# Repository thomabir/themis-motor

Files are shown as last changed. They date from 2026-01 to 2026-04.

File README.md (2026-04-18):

# Themis Telescope Mount

Hardware and software for a direct-drive brushless DC motor and encoder for a telescope mount

## Control Scheme

- PWM
  - 50 to 100 kHz
  - Input: desired PWM duty cycle
  - Output: PWM signals to gate drivers
- Inner Loop: Current Control (FOC)
  - Controls flux and torque currents.
  - Runs at 10–20 kHz.
  - Inputs: Torque target (from position control loop), Phase current measurements (from current sensor), rotor electrical angle (from encoder).
  - Outputs: PWM duty cycles via inverse Park/Clarke
- Outer Loop: Position Control
  - Controls angular position and/or velocity, which is commanded from the observatory
  - Runs at 100–500 Hz.
  - Inputs: Position setpoint, measured position from encoder
  - Output: Torque command

## Motor Specifications

- Type: BLDC, direct drive (salvaged from a hoverboard)
- Quantity: 2 motors
- Electrical: 3 Phases, 30 Poles, 27 Slots, 36 V, 13 A RMS peak, 7A RMS continuous, 0.45 Ω, Y
- Mechanical: ≈ 10 Nm continuous, ≈ 1.43 Nm/A, ≈ 16 rpm/V, 350 W (estimates, not necessarily accurate)

## Encoder

DIY inductosyn, 0.05 arcseconds resolution, 1000 Hz sampling rate, custom SPI-like interface with absolute position, latency 1 ms.

## System Requirements

- Telescope Alt/Az axis control
- Tracking speed: 1 rev / 24 hr
- Slewing speed: 1 rev / 10 s
- Tracking error: < 1 arcsecond RMS
- Power: Mains
- System inertia: Low (balanced 8" SCT)

Thermal: motor will be at low currents most of the time, so convection will probably be fine, with short peaks when slewing. (Motors are from a hoverboard, which was also only passively cooled)

Mechanical: Very low backlash; bearing friction (esp. static) likely to influence control scheme.

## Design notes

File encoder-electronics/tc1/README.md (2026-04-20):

# Themis TC1

Goal: Figure out whether 10 kHz amplitude modulaiton works with the AD9834 DDS via the FS_ADJUST pin.

Secondary goal (optional): Have a minimal "sender" circuit for the encoder, test the differential driver

- Interfaces:
  - Power in: 4V lab PSU, ±13V lab PSU
  - Signal out: differential amplified DDS signal, can power the existing encoder coils
  - Digital IO: Every useful digital pin from the DDS is accessible via a pin header, for easy debugging
  - Testpoints: Every single analog signal is accessible, and jumpers between main sections are used for easy disconnecting of blocks.

- Strategy
  - Passives: Use 0Ωs and DNPs to keep it flexible. 0805 everything for easy modification by hand.
  - Using screw terminals for power and encoder, pin headers for digital. Not fancy, but cheap and quick.

- Power:
  - ±12 V: LT3097
    - 10 CHF/pc (= 5 CHF/rail)
    - 500 mA bipolar adjustable ultra-low-noise LDO
    - It's the best. Slightly pricy, but just works, no fuss.
    - Basically excludes LDOs as a noise source -> faster prototyping.
    - (Hurts a bit to buy fancy parts for a prototype)
  - 3.3 V: MAX8887
    - I've used it before -> copy-paste design
    - Decently low-noise
- DDS: AD9834
  - The big unknown: Can it modulate quickly and with low noise?
  - Does the differential output work as expected?
  - How to program it? Will figure out once I get it
- Clock: Active crystal oscillator at 75 MHz
- Diff-amp to drive encoder: AD8390
  - Lots of power, cheap, fast
  - Unknown: Made for ADSL, let's see if this works well in this application? Spec wise, it should work.

## How to run

Upload code to Teensy: `~/.platformio/penv/bin/pio run -e teensy41 -t upload`

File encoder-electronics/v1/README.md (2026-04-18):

# Themis Encoder Controller V1

A prototype board to prove the encoder concept.

Goal: Measure at the precision required for telescope tracking. Find the limiting factors.

## Concept

- Generate two 0.6 Vpp sines with DDS, in the 100 kHz to 3 MHz region (λ/10 < 5 m)
  - TX1: f0 carrier, amplitude modulated with f1, resonant with the encoder
  - TX2: f0 carrier, amplitude modulated with f2, resonant with the encoder
  - keep f2, f1 < 20 kHz, such that it's comfortably in the 32 kHz BW of the ADC
- Amplifiy all to 5 Vpp, 50 mA compliance
- TX signals are fed into the encoder via STP instrumentation cables
- RX signals are fed out of the encoder with STP instrumentation cables
- A differential amplifier receives the RX signals and amplifies them to a few Vpp (variable gain, depending on encoder used)
- Two mixers demodulate the AM signals
- An active band-pass filter removes the LO and DC and outputs the signal in ± 1V range
- A simultaneous sampling sigma-delta ADC samples the downmixed RX signals
- The uC demodulates in the digital domain
- The DDS clock and ADC sampling are phase-coherent, such that the freuquencies arrinving at the uC are deterministic.

## Advantages

- Processing at AC instead of at DC -> no susceptibility to slow drifts and 1/f noise
- High pole count -> higher resolution and lower susceptibility to random errors
- Tuned RF section for highest coupling efficiency, and low coupling of noise at other freuquencies

## Challenges

- Clocks synchronization strategy for DDS, ADC, uC etc.
  - The DDSs run on their own clocks (e.g. from clock generator), small drifts don't matter
  - The uC generates
    - a 8.129 MHz for the Sigma-Delta ADC clock
    - the PWM signals that control the amplitude modulation of the DDSs
      - the sin/cos LUT used for demodulation are also used for generating the PWM amplitude modulation signal
  - The uC runs on its own clock, and samples on /DRDY from the ADC (interrupt)
- crosstalk between all pairwise combinations of the four channels (2x RX, 2x TX) has to be low, so good shielding is essential
  - Be aware of returns currents in the ground plane
- It might be hard to get the analog signal chain right the first time on the PCB, without prototyping on breadboard first
  - Put [pin headers](https://www.digikey.ch/de/products/detail/w%C3%BCrth-elektronik/61300211121/4846823) and [jumpers](https://www.digikey.ch/de/products/detail/sullins-connector-solutions/QPC02SXGN-RC/2618262) on every important signal and power connection, such that it is essentially modularized
  - Can easily probe sections in isolation without having to cut traces or desolder

## Key components

### Power (LDOs)

### Signal generation

Requirement: Up to 3 MHz sine.

#### DDS

- Current choice: [AD9834](https://www.analog.com/media/en/technical-documentation/data-sheets/AD9834.pdf)
  - 14 CHF * 2 = 28 CHF total
  - Supply 2.3 to 5.5 V (AVDD and DVDD indpendent)
  - 75 MS/s, 10 Bit
  - 2.5 MHz signal: strongest image -30 dB
  - MCLK: up to 75 MHz
  - Vout: 30 mV to 0.6 V
  - It has an FSadjust pin, which can be used for amplitude modulation
    - App note: [It works at DC](https://www.analog.com/media/en/reference-design-documentation/reference-designs/cn0156.pdf)
    - May have to decrease COMP cap for 10 kHz modulation: [EEVblog forum](https://www.eevblog.com/forum/projects/amplitude-modulation-of-ad9834-dds-failed-but-why/25/)
    - Differential outputs: [EEVblog forum](https://www.eevblog.com/forum/repair/low-cost-signal-generator-with-modulation-is-that-a-pink-elephant)
- AD9838
  - BW: 8 MHz
  - 7 CHF
  - no FS ADJUST -> not an option
- AD9837
  - 6 CHF, hard to notice any practical difference to AD9838
  - 8 MHz bandwidth
  - 0.6 Vpp typ
  - 200Ω Rout (current source with 200Ω to ground after it -> Thevenin is a voltage source with 200Ω output impedance)
    - needs a buffer to drive the encoder (1µH, 1Ω, 1nF)
  - has image at nyquist - fout, but that will be filtered out during downconversion
    - however, LO has to be clean. Should think about this a bit more
  - 2.5 MHz signal: strongest image at -15 dB, 13.5 MHz
  - 2.3 to 5.5 V power supply
  - No FS ADJUST -> not an option

#### Clock generator

- [TI CDCE6214](https://www.ti.com/lit/ds/symlink/cdce6214.pdf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)
  - 5.70 CHF
  - same as in analog discovery 3
- [Si5351A](https://cdn-shop.adafruit.com/datasheets/Si5351.pdf): 1.7 CHF, can generate 4 clocks from kHz to 10s of MHz
  - [Adafruit breakout board](https://www.adafruit.com/product/2045)
  - Z_out: 50 Ω
  - Supply 3.3 V
  - RMS phase jitter (12 kHz to 20 MHz): 3.5 ps typ
  - Pk cycle-to-cycle jitter (10 k cycles): 30 ps typ
  - Crystal requirements: 25 to 27 MHz, 6 to 12 pF

### Amplifiers

- Requirement
  - Gain 10 at 3 MHz (30 MHz GBWP)
  - Slew rate: `2π * 5V * 3 MHz` = 100 V/µs
  - Power: ±18 V min.
- Main op-amp: [LM6172](https://www.ti.com/lit/ds/symlink/lm6172.pdf)
  - stable with 1 nF load
  - dual opamp
  - -65 dB crosstalk rejection at 3 MHz
  - fast enough
  - 50 mA continuous output current
  - DIP package available for easy breadboarding
  - 33 CHF for 10 pc
- stronger TX amplifier/buffer: OPA2673
  - Supplies: ± 3.5 to ± 6.5 V -> analog chain is ± 5 V, because nice number
  - Output: 700 mA, 3500 V/µs (way overpowered most likely, very conservative)
  - 600 MHZ unity gain bandwidth
- full-wave diode mixer (can be skipped with jumpers, then can use breadboard mixer as alternative)

### ADC

- [ADS131M03](https://www.ti.com/lit/ds/symlink/ads131m03-q1.pdf)
  - 3ch 64 kS/s Sigma-Delta
  - 8.192 MHz MCLK in
  - Supply: 2.7 to 3.6 V -> using 3.3V
  - Integrated charge pump to allow negative input voltages
    - Note that this is unusual, but simplifies the setup considerably.
    - Max absolute ratings on AINP, AINN: AGND – 1.6V to AVDD + 0.3V
    - Recommended voltage  on AINP, AINN: AGND – 1.3V to AVDD
    - Current limit to ±10mA max: ±6V into 1kΩ yield 6mA, should be safe
  - Integrated reference: 1.2V
  - Full scale range: ±1.2V (1x gain) to ±9.3mV (128x gain)
  - 330 kΩ input impedance at gains from 1 to 4
  - Noise and dynamic range (p. 16 datasheet)
    - At  1x gain, 64 kS/s: 80 dB dynamic range, 75 µV RMS noise
    - At 32x gain, 64 kS/s: 60 dB dynamic range, 5.58 µV RMS noise
    - don't go higher in gain, no benefit
  - channel corsstalk < -125 dB
  - power: < 3mA analog, < 0.5 mA digital apparently (p. 15 of datasheet)

## Signals and noise

- DDS: 600 mVpp (300 mV amplitude)
- TX amps: amplify to 5 Vpp
- encoder board: 0.3x gain (measured at 2.5 MHz with 10 nF, see lab notebook 2025-11-03)
- RX amps: switchable from 1x to 10x gain (or potentiometer)
- model mixer in LTspice, then low-pass
- ADC: ± 1 V amplitude target pseudo-differential (connect GND to AINN) (headroom to ±1.2V reference)

## Power and voltages

- Analog voltages: ±9V (except ADC)
- ADC and DDS: +3.3V (both analog and digital)
- ADC inputs ±1.2V differential max.
- Protect ADC against overvoltage

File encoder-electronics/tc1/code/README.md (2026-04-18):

# TC1: DDS

## Concept

Outputs:

- 8.192 MHz clock for ADC
- 2x PWM signals for FS_ADJUST (kHz to 10 kHz range)

Inputs:

- Data_Ready from ADC (≈ 64 kHz, the ADC derives it from the 8.192 MHz clock)
- SPI data from ADC

Setup:

- Populate LUTs for FS_ADJUST
- Start ADC clock

Main loop (no DMA):

- Wait for DREADY
- Read ADC
- Demodulate and downsample data (using LUT values)
- Load new duty-cycle for FS_ADJUST from LUT

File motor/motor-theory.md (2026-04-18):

# Motor Theory

Torque equation:
$$
T = \frac{3}{2} p \phi I
$$

## Derivation of torque equation

The net power flow of the system is the following:
Electrical power enters the system, and it leaves as mechanical power and thermal power.

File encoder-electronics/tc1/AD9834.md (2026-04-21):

# AD9834 DDS — Field Notes

MCLK on TC1: **75 MHz** (BOM correct, schematic had 50 MHz — corrected).

SPI interface: SCLK idles high, data latched on falling edge, MSB first, 16-bit words, write-only (no MISO).
notFSYNC (active low) frames each 16-bit transfer individually.

The AD9834 datasheet describes this as CPOL=0, CPHA=1 — which is **opposite** to the Arduino/standard convention. In Arduino terms this is **SPI_MODE2** (CPOL=1, CPHA=0). Use `SPI_MODE2` in `SPISettings`.

## Register addressing (DB15:DB14)

| DB15 | DB14 | Target |
|---|---|---|
| 0 | 0 | Control register |
| 0 | 1 | FREQ0 |
| 1 | 0 | FREQ1 |
| 1 | 1 | PHASE (DB13 selects PHASE0/PHASE1) |

## Control register (DB15:DB14 = 00)

| Bit | Name | Description |
|-----|---|---|
| DB13 | B28 | 1 = 28-bit frequency write (two consecutive 16-bit words, LSB first then MSB). 0 = 14-bit half-word mode (use HLB to select half) |
| DB12 | HLB | When B28=0: 1 = write MSBs, 0 = write LSBs. Ignored when B28=1 |
| DB11 | FSEL | 0 = use FREQ0, 1 = use FREQ1 in phase accumulator |
| DB10 | PSEL | 0 = use PHASE0, 1 = use PHASE1 |
| DB9 | PIN/SW | 0 = software control (use control bits), 1 = hardware pin control |
| DB8 | RESET | 1 = reset internal registers → DAC output at midscale |
| DB7 | SLEEP1 | 1 = disable MCLK |
| DB6 | SLEEP12 | 1 = power down DAC |
| DB5 | OPBITEN | 1 = **enable SIGN BIT OUT pin**. Must be 0 if MODE=1. Pin is high-Z when 0 |
| DB4 | SIGN/PIB | 1 = comparator output on SIGN BIT OUT, 0 = MSB (or MSB/2) of DAC data |
| DB3 | DIV2 | When SIGN/PIB=0: 1 = MSB direct, 0 = MSB/2 |
| DB2 | — | Reserved, always 0 |
| DB1 | MODE | 0 = sine (SIN ROM active), 1 = triangle (SIN ROM bypassed). Must be 0 if OPBITEN=1 |
| DB0 | — | Reserved, always 0 |

Useful control word constants:

| Value | Effect |
|---|---|
| `0x2100` | B28=1, RESET=1 — reset device |
| `0x2000` | B28=1, FSEL=0, sine output, SIGN BIT OUT disabled |
| `0x2002` | B28=1, FSEL=0, triangle output (MODE=DB1), SIGN BIT OUT disabled |
| `0x2800` | B28=1, FSEL=1, sine output, SIGN BIT OUT disabled |
| `0x0028` | OPBITEN=1 (DB5), DIV2=1 (DB3) — SIGN BIT OUT at f_out (no B28, use as tail-word in freq update) |
| `0x0038` | OPBITEN=1 (DB5), SIGN/PIB=1 (DB4), DIV2=1 (DB3) — SIGN BIT OUT via comparator (VIN path) |

## Frequency registers

With B28=1 (28-bit mode), write two consecutive words to the same register address:
1. First word: `reg_addr | (freq_word & 0x3FFF)` — 14 LSBs
2. Second word: `reg_addr | ((freq_word >> 14) & 0x3FFF)` — 14 MSBs

Frequency word: `freq_word = round(f_out / f_MCLK * 2^28)`

Example for 1 MHz with 75 MHz MCLK: `freq_word = 3,579,139`

## SIGN BIT OUT (SIGNOUT) pin

**SIGNOUT is high-impedance at power-up** (OPBITEN=0 default). Any signal seen on it before config is parasitic coupling on the floating pin — not a real output.

To enable: set OPBITEN=1 in control register. MODE must be 0.

SIGN/PIB=1, DIV2=1 gives a comparator-derived square wave — useful as a quick proof-of-life check at the DDS output frequency.

## FS_ADJUST pin

Analog input setting full-scale DAC output current:
`I_OUT_FS = 18 × V_FSADJ / R_ADJUST`

Datasheet default: 6.8 kΩ from FS_ADJUST to AGND.
On TC1: driven by Teensy PWM (pin 6) through an on-board low-pass filter. Disconnect or float FS_ADJUST only temporarily for debugging; the full-scale current is undefined when floating.

## Startup sequence

1. Assert RESET: send `0x2100`
2. Write frequency register (two words for 28-bit mode)
3. Write phase register if needed (default 0 is fine)
4. Deassert RESET and configure output: e.g. `0x2028` (sine, SIGNOUT enabled via comparator)

## TC1 wiring (Teensy 4.1 → board header)

| Board pin | Teensy pin | Function |
|---|---|---|
| SDATA | 11 | MOSI |
| SCLK | 13 | SCK |
| notFSYNC | 10 | CS (active low) |
| RESET | 9 | GPIO — **must be driven LOW (OUTPUT) before initialising DDS** |
| FS_ADJUST | 6 | PWM output |

## Known issues / lessons learned

- **RESET pin must be driven LOW before initialising the DDS.** A floating RESET pin held the chip in reset throughout TC1 bringup — all SPI writes were ignored, SIGNOUT was silent. Root cause: the AD9834 constructor was also being called at global scope (before Arduino `setup()`), meaning SPI was not yet initialised. Fix: construct the DDS object inside `setup()`, and drive RESET LOW explicitly before doing so.
- SIGNOUT must be broken out on the next board revision — essential for proof-of-life since the AD9834 has no readback (SPI is write-only).
- **SIGNOUT is high-Z at power-up** (OPBITEN=0). Any signal seen before config is parasitic coupling on the floating pin. Silence after config means OPBITEN was never written — check SPI first.
- ~~The library's `update_freq_reg` ends with control word `0x38` (OPBITEN=1, SIGN/PIB=1, DIV2=1, B28=0, FSEL=0). This enables SIGNOUT as a comparator output but leaves B28=0 after each call.~~ **Fixed (2026-04-21):** the FSELECT-switch tail-word is now built from named bit constants and carries the current output mode correctly. B28 is no longer cleared after a frequency update.
- The AD9834 uses a non-standard CPOL/CPHA labelling (CPOL=0, CPHA=1 in their docs = Arduino SPI_MODE2). Don't set the SPI mode from the datasheet labels directly.
- Digital supply current: ~13 mA idle, ~17 mA when DDS is active and outputting.

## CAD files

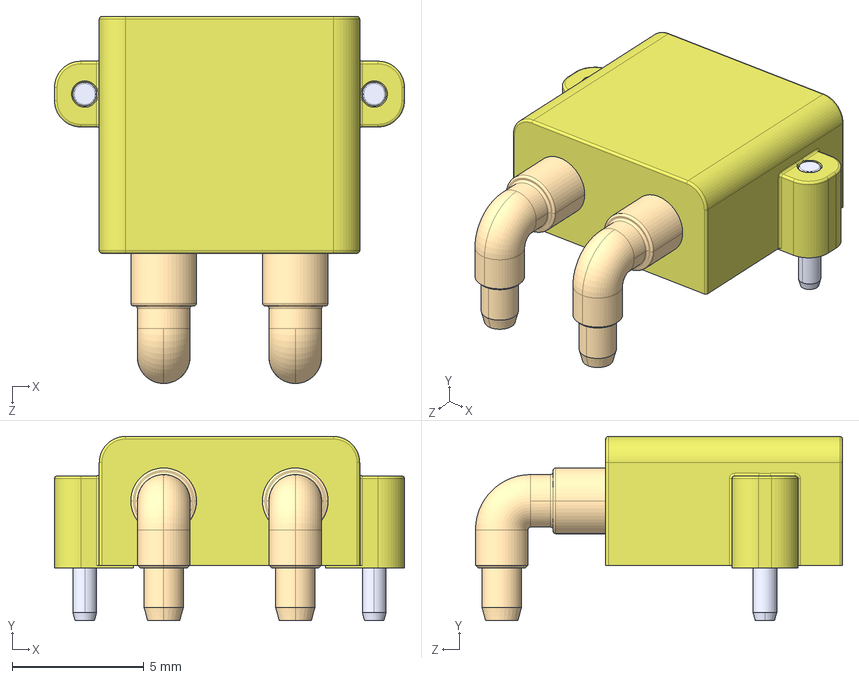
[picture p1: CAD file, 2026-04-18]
motor-controller/v3/kicad/3d-models/XT30PW-M.STEP
13.3 x 7.00 x 14.0 mm

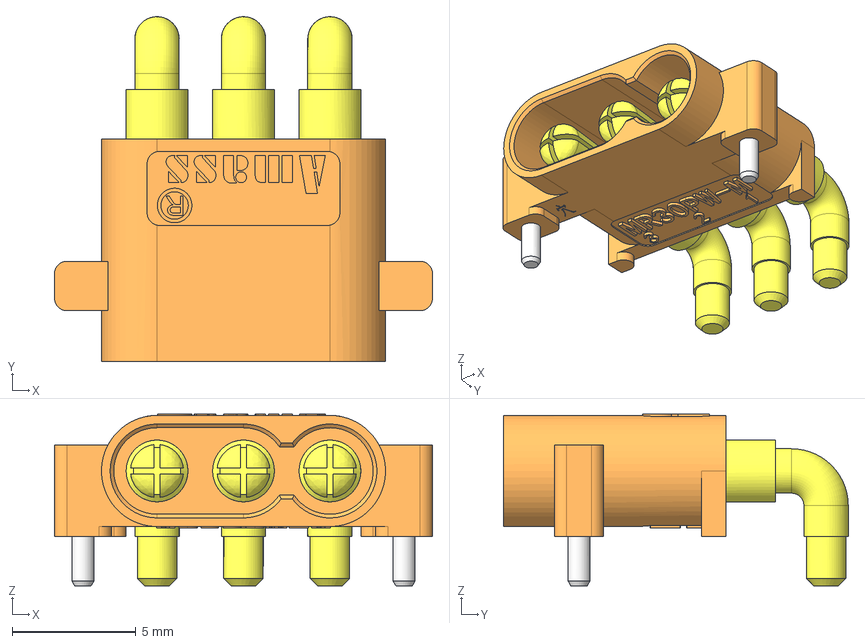
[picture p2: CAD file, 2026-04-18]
motor-controller/v3/kicad/3d-models/MR30PW-M.step
15.3 x 13.9 x 6.95 mm

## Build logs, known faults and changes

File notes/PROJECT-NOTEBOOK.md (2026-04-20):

# Themis Project Notebook

## 2026-06-20

### Getting 1 MHz DDS output

- Measured clock: 75 MHz, ≈ 3 Vpp (not great probing, so amplitude not certain)
  - Problem: This is a discrepency with schematic, which says 50 MHz. Not a big issue
  - BOM part number is a 75 MHz part, so the procurement was correct. Updating schematic.
  - Changed MCLK_HZ in code to 75 MHz
- Measuring SIGNOUT pin
  - 8.7 MHz 3.3V clock, distorted probably from bad probing
  - After configuring for 1 MHz with Teensy: Still 8.7 MHz.
  - This is not as expected, something's wrong. Should be 1 MHz
- Soldered 6.8 kΩ resistor between FSADJUST and GND.
- Clock still as before
- SIGNOUT now no output, both before and after config from uC.
- Did the part die?
- Prepared second board, also soldered in 6.8 kΩ resistor between FS_ADJUST and GND
  - Clock good
  - no SIGNOUT output before teensy config
  - no SIGNOUT output after teensy config
- Removng 6.8 kΩ resistor again
  - clock still good
  - still no SIGNOUT output
- What happened here? Did both boards die from soldering in a resistor?

- Desoldered 6.8 kΩ again on one of the boards. I broke out these pins on the PCB, so the resistor has big pads and is nowhere near the IC. No bridges possible here
- Inspected both boards under microscope. No problems visible. Some crud from probing the SIGNOUT pin at the IC (forgot to break that one out), but no bridging. Cleaned up a bit anyway with small scaper.
  - Next board iteration: break out SIGNOUT pin
- ICs are not getting warm. Lab PSU shows < 10 mA on analog rails. No current measurement on digital rails unfortunately. Switching Lab PSU to get that as well.
- Digital rail draws 13 mA, probably not a short.
- Next: Checking SPI

- From AD9834 datasheet:
  "SIGN BIT OUT PIN
  The AD9834 offers a variety of outputs from the chip. The digital outputs are available from the SIGN BIT OUT pin. The available outputs are the comparator output or the MSB of the DAC data. The bits controlling the SIGN BIT OUT pin are outlined in Table 17.
  This pin must be enabled before use. The enabling/disabling of this pin is controlled by the Bit OPBITEN (DB5) in the control register. When OPBITEN = 1, this pin is enabled. Note that the MODE bit (DB1) in the control register should be set to 0 if OPBITEN = 1."
- It appears what I measured before (8.7 MHz SIGNOUT) may have been some parasitic coupling.

- Scoping SPI signals with AD3 now to see if they are as expected.
- Not stable, very noisy, one capture:
  `h4101 h1907 h01B5 h1971`
  SCLK freq ≈ 10 MHz
- Weird, I've used 10 MHz SPI over jumpers in the past, no problem.
- SPI clock slowed down to 1 MHz
  - still garbled data, changes on every transmission
  - Disconnected DUT now - just probing SPI from teensy directly.
  - That clock frequency is not a problem now - 1 MHz is very slow
- Found a problem: was probing SPI wrong. In AD9834 datasheet: "SCK idles high between write operations (CPOL = 0), Data is valid on the SCK falling edge (CPHA = 1). notFSYNC (active low) frames each 16-bit transfer individually."
- When I set the logic analyzer up for that, it's a bit more stable:
  ```
  b0010000000000000
  bXX01110100000011
  bXX00000011011010
  b0000X00000111000
  ```
  (X means unstable, jumping around)

- Just realized: RESET pin was floating the entire time. Setting it now and reuploading code.
- SIGNOUT is alive! 9.7 MHz 3.3V
- Power consumption just changed: 17 mA digital.
- DDS+ and DDS- show a clean 1 MHz signal!
- That fixed it, floating reset pin was the culprit.

### Testing amplifier function

- I get a clean 1 MHz signal between the AMP+ and AMP- pins
  - 10.45 Vpp, 3.67 Vrms
- Good output at output terminals (after resonant capacitor)
  - 10.35 Vpp, 3.64 Vrms

### Testing modulation via FS_ADJUST

- Signals from PWM + low-pass appear quite noisy. Push PWM freq. as fast as possible.

### Notes for the future

- What worked well
  - Power section: flawless so far
  - Having lots of GND testpoints, very convenient
  - Breaking out many signals as testpoints - makes probing easier, but also soldering in other components like R_SET

- What to improve
  - make connectors (power, data) quick-disconnectable (use the plug-in type screw terminals instead of regular ones)
  - Break out more pins for easy testing, especially for unknown ICs
  - Leave some footprints to be able to set up ICs with "default" components, in case my config does not work, and mark as DNP
  - Cross-check BOM with schematic (50 vs 75 MHz clock)
  - Don't leave the reset pin floating

## 2026-04-18

TC1 testings

[X] Voltage regulators are working
  [X] +12 V (less than 10 mA idle)
  [X] -12 V (less than 10 mA idle)
  [X] +3.3 V

Should have broken out the SIGNBIT pin from the AD9834 for proof-of-life, since there is no SDO.

Currently, using datasheet-suggested 6.8 kΩ resistor from FSADJUST to GND instead of PWM.

Setting up for 1 MHz sine wave. Output not good. See spikes at 1 MHz, but a lot of noise. Not a sine wave.

## 2026-04-17

Assembling TC1 (Transmitter)

Ibom had some wrong values, used to ones from the schematic instead.
  For C13, I'm using 10u instead of 2.2u
  For R12, R13 I'm using 22 Ω instead of 25 Ω

## 2026-01-01

TC1 sent off for manufacturing.
RX: Using AD8130 in-amp. Rest of chain I have in LTspice, still need an opamp choice, but not critical.
Work on ADC, schematic etc.

Firmware for DDS and ADC.

## 2025-12-30 Test Coupon 1: DDS Amplitude Modulation

Goal: Figure out whether 10 kHz amplitude modulaiton works with the AD9834 DDS via the FS_ADJUST pin.

Secondary goal (optional): Have a minimal "sender" circuit for the encoder, test the differential driver

- Interfaces:
  - Power in: 5V lab PSU
  - Signal out: amplified DDS signal, can power the encoder
  - Digital IO: Every single digital pin from the DDS is accessible via a pin header, for easy debugging
  - Testpoints: Every single signal is accessible, and jumpers between main sections are used for easy disconnecting of blocks.

- Power:
  - LDO for 5V -> 3.3V to supply DDS
  - LDO for ±X V -> supplies amplifier

## 2025-12-29 Getting un-stuck

- To avoid analysis paralysis, I have to get a board out for manufacturing soon.
- I'm setting a hypothetical hourly rate for myself, to avoid spending too much time in simulation and concept phase.
  - 10 CHF set-up fee (whenever I start working or thinking on the project)
  - 30 CHF/hour (min. 1h)
- Deadlines
  - [DONE] Today (Dec 29), I have identified the SGU (Single Greatest Unknown), and dedicate to building a TC (Test Coupon) to test this specific thing.
  - [TODO] Sunday 20:00 (Jan 4) at the latest, I send out Test Coupon #1 for manufacturing. If this does not happen, I trash the project.

- SGU (Single Greatest Unknowns):
  - Candidates:
    - Analog part choice
    - Filters
    - noise
    - amplification
    - oscillation/stability
    - uC interface to ADC/DAC
    - Power supply
    - Mounting/mechanical
    - DDS control via modulation port
    - Clock generator for DDS
    - Clock synchronization (DDS modulation -> ADC Sigma-Delta sampling clock)
    - uC internal code (DSP etc.)
    - Current return path / ground noise
    - Interference/EMI
    - Cables/shielding
    - Connectors
    - Encoder coils analog model
  - Shortlist:
    - Analog chain concept: Get a signal from a signal generator, amplify it to get it into the encoder, amplify and mix down the response, look at it on the scope. NO: I basically already did that on breadboard, only one buffer was missing honestly. I have high confidence this will work. I trust the concept.
    - Analog chain implementation: Instead of breadboard, use the real SMD components, characterise the noise levels, test the amplification gain of the stages. Make sure nothing oscillates. No digital parts on board. NO: I realise I am mostly anxious to test the digital part, which I don’t have any experience with.
    - Digital section: I have never worked with a crystal oscillator before (shocking, I know), and I have two DSS’s and an ADC, all of which need sync’d clocks or control inputs from the uC. Goal: Get the individual digital parts working with their clocks synchronised and correct control signals from the uC. Slap on a basic analog section, first guess, and be ready to just swap out the analog part for something better in a separate TC. Just measure SOMETHING on the ADC that shows that the clocks are in phase, disregard noise. Use a Teensy dev-board
    - No, keep it even simpler: Make a AD9834 Test Coupon: Just the DDS, a basic amplifier for the output, and break out every single pin. This is the “warm-up” exercise. Goal: Get the amplitude modulation working with the FS_ADJUST pin. EEVblog forum members write that I may have to reduce COMP capacitor to make it work for my modulation frequency. This is something that I can’t figure out in LTspice, the datasheet does not mention it, thus it needs a physical test board. It’s crucial to figure this out: The encoder concept depends on being able to modulate the DSS output at 10 kHz or so. If it works: use it as a small board that is part of the encoder, or copy-paste the PCB design in with confidence wherever needed. If it doesn't work: I saved a lot of design time by identifiying the cuplrit early, the rest of the encoder would not have worked anyway!

- Oscillators 75 MHz for DDS: [digikey](https://www.digikey.ch/de/products/filter/oszillatoren/172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)

## 2025-12-02

- Finished analog chain in LTspice
- Mixer works at 200 kHz as well as 2.5 MHz, that part should be fine
- The only adjustable gain I need is at the RX amp, since it depends strongly on encoder size.
- PCB layout plan
  - Put everything on one PCB, 10x10 cm minimum size (larger is fine for easier bodging)
  - Separate into logical sections: DDS/ADC/clock generator/analog chain
    - Connect with traces that have a jumper on them, so can easily interrupt traces and connect other signals
    - (SMT jumpers would be great to save time)
    - this keeps it modular and still functional, even if part of the board fails

## 2025-11-30

Laying out the analog board in LTspice, selecting gains.
Considering the LM6172 as the do-it-all amplifier (50 mA current, fast, drives 1nF well)

## 2025-11-03

- Continued from yesterday
  - Realised I used 1 nF caps instead of 10 nF yesterday.
  - If I use 10 nF for sender and receiver, 10Ω series at sender for current limit, I get the expeceted peak around 2.5 MHz, gain ≈ 0.35 peak.
  - Still weaker than what I had on 2025-08-11, but at least there's a peak and it's at the expected frequency.
  - K ≈ 0.1 in LTspice seems a decent match for the behaviour I see.

Does this give me all the information I need to prototype the analog chain?

- Max. frequency and bandwidth: yes, 2.5 MHz should be fine, let's say 3 MHz for margin.
- LTspice model: yes, I have one that seems to reproduce the behaviour well (two 500 nH inductors, K = 0.1)
- Capacitors for resonant circuit: 10 nF on RX and TX
- Current compliance: Get it from LTspice model, AD3 had no problems in resonance with 1Vpp + 10Ω series resistor
- Noise levels: Don't know yet, best to build a prototype and measure.

So, what is the next step?

- Analog chain prototype: Gain stages, mixers, testpoints.
  - Frequencies come from a different board or AD3/signal generator
  - ADC also on a different board, differential via STP wire
- In more detail
  - Three input ports for TX1, TX2, LO
  - Power amplifiers for TX1, TX2 (+LO, might as well):
    - DDS output is in the range of 0.6 Vpp + 200 Ω impedance
    - Selectable gain with resistor or jumper: 1x, 5x, 10x?
    - current compliance 100 mA is plenty
    - voltage level? 3.3 V would be nice as it's universal, but analog chain may well be ±12 V or so if needed.
  - Outputs for amplified TX1, TX2: STP wire
  - Inputs for RX1, RX2
  - Amplifiers for RX1, RX2: not much power needed (driving diodes, see LTspice), selectable gain again. May be worth making these differential, not sure
  - Diode mixers with LO: double Schottkys for maximum efficiency
  - Low-pass filter: Prepare for a 64 kS/s sigma-delat ADC, so 100 kHz filter more than adequate.
    - Blessed art thou, sigma-delta ADC, for thy inherent filtering simplifies my analog chaine
  - That's all, folks.

Potential pitfalls

- Interference, crosstalk: Keep everything well separated, lots of ground planes, use STP wires.
  - 3 MHz is a long wavelength, lambda/10 ≈ 10 m
- Noise
  - measure and adapt, check with LTspice. Trust the physics
- PCB errors
  - Keep it modular: testpoints and jumpers everywhere, so every module can be skipped and isolated
  - keep the PCB big, so repairs and bodges are feasible
  - Use parts that I can hand-solder if neeeded (0805, SOIC ...)
- Oscillations, capacitive loads
  - Use recommended isolation resistors at TX amps for capacitive loads
  - Keep feedback loops tight
  - simulate in LTspice

What I need

- STP wires + some way to connect them to the board. Maybe just screw terminals + a crocodile clamp for shield to keep it simple.
- Decide on diff-amp vs opamp at RX: what are the trade-offs?
- PCB design + reflow

## 2025-11-02

Goal: Figure out the information I need to design the encoder board.

- Measure transfer function of current encoder, in a configuration that would be used for practical motor control.
  - This defines the maximum required frequency of the signal generators, as well as the minimum expected coupling
  - (A larger encoder will resonate at a lower frequency and have better coupling coefficient)
  - Read through lessons learned of previous attempts at measuring the encoder, make a checklist.
- Build up the whole system as far as possible.
  - What is missing? Probably need buffer amps: How much gain, bandwidth, current compliance needed? Which capacitive + inductive load?
  - How are the noise levels? Probably insufficient -> where does the noise come from? Cables? DDS? ICs?

### Encoder characterisation measurements

Goals: Get all information I need to design encoder electronics that interfaces with the encoder disks (DDS, RX and TX amplifiers)

This means I need:

- Measurements of L, R, C of the encoder (no resonant circuit, with resonant circuit)
- Measured impedance curve of encoder (no resonant circuit, with resonant circuit)
- Choice of capacitor/inductor to make the encoder resonant
- LTspice model of single encoder disk (no resonant circuit)
- LTspice model of full encoder system of two disks (no resonant circuit)
- Measured transfer function of two coupled disks under maximum coupling

Watch out:

- Keep wires short to avoid their parasitic impedance
- Use short/open compensation
- Check crosstalk and keep it low, this messed up some previous measurements
- Find optimum configuration with resonant circuit, then characterize.

Experiment 1: Impedance measurement of single encoder disk

- Used Analog Discovery 3, impedance measurement mode, 10 Ω resistor
- performed open and short calibration
- Sweep 1 kHz to 10 MHz with 1 V amplitude
- Results
  - Series inductance 0.4 µH to 0.6 µH from 10 kHz to 10 MHz
  - Series resistance: 0.9 Ω to 1.0 Ω from 10 kHz to 2 MHz, sharp rise afterwards
- The resistance is as expected constant and low. The rise at the end is weird
- Inductance is as expected constant and low (small encoder).
- Measurements agree with my previous measurements on 2025-05-17 of the same encoder, except for series inductance (was 0.65 to 0.75 µH).
  - I did however shorten the cables of the encoder from 40 cm to 20 cm today.
- Conclusion: use 0.5 µH series impedance + 1.0 Ω series resistance for modelling the disk.

Trying to reproduce 2025-08-11

- No resonant circuit: Hard to measure, around 0.6 V/V at 4 to 5 MHz is peak coupling.
  - Used a 10 Ω resistor in series with source, 1V amplitude. Still lots of distortion at lower frequencies.
- With resonant circuit, 10 nF in parallel with both sender and receiver
  - Very weird! I don't get a resonance peak. Very suspicious, probably something wrong here.
    - Looks like resonance at ≈ 10 MHz with 1:1 coupling
    - Nevermind, just crosstalk, signal remains even when I unplug the measurement leads on the RX
  - Should try with inductor as well, maybe that fixes it. But have I really forgotten to write that down in the entry from 2025-08-11?
  - I don't see a match with f0 = 1 / 2π sqrt(LC), very odd! This is not a missing inductor, something different is wrong here.

### Encoder analog chain prototype

Goal:  Get all information I need to design encoder electronics

This means I need:

- Try to build the full analog chain
- Check where I need additional gain or current compliance
- Measure noise and compare with expectation

## 2025-10-20

Have to figure out what voltage levels I expect at the RX: Do I need an amplifier/buffer there?
Should find that experimentally with the encoder I have.

## 2025-10-19: Solving the synchronisation problem

New maxim: Optimise for finishing, not for cost/time/effort

- Don't try to save money
- Use components that are easy to use (low pin count)
- Make recovery from mistakes easy
- uC/FPGA on external dev-board, header pins
- jumper-friendly PCBs such that broken sections can be skipped and replaced with breadboards
- use good cables and connectors to reduce mess and interference
- Use familiar tools (Zynq, lab pc, ImGui)

**Proposed solution for the clock synchronization problem:**

- A clock generator IC generates four signals
  - 50 MHz clock for a DDS, to generate a clean LO free of harmonics
  - f1 for the encoder (square wave) (or use DDS as well)
  - f2 for the encoder (sqaure wave) (or use DDS as well)
  - 8.129 MHz for the Sigma-Delta ADC clock
- The microcontroller or FPGA runs on its own clock, and samples on /DRDY from the ADC (interrupt)
  - The internal sin/cos LUT also is incremented at every /DRDY pulse
  - Or can also get it from clock generator, but for modularity's sake, I'll keep them separate until the design is more mature.

**Boards for prototyping:**

- PYNQ Z2 dev board for FPGA
- Custom PCB
  - Power (LDOs), external
  - Clock generator: Si5351A
  - DDS: AD9834
  - TX amplifiers/buffers: OPA2673
  - RX buffer: same or something less powerful
  - full-wave diode mixer (can be skipped with jumpers, then can use breadboard mixer as alternative)
  - ADC: ADS131M03 (3ch 64 kS/s)

The third ADC channel would be unused in this design, and could be used to make the encoder absolute with an additional basic low-resolution encoder with different pole count.

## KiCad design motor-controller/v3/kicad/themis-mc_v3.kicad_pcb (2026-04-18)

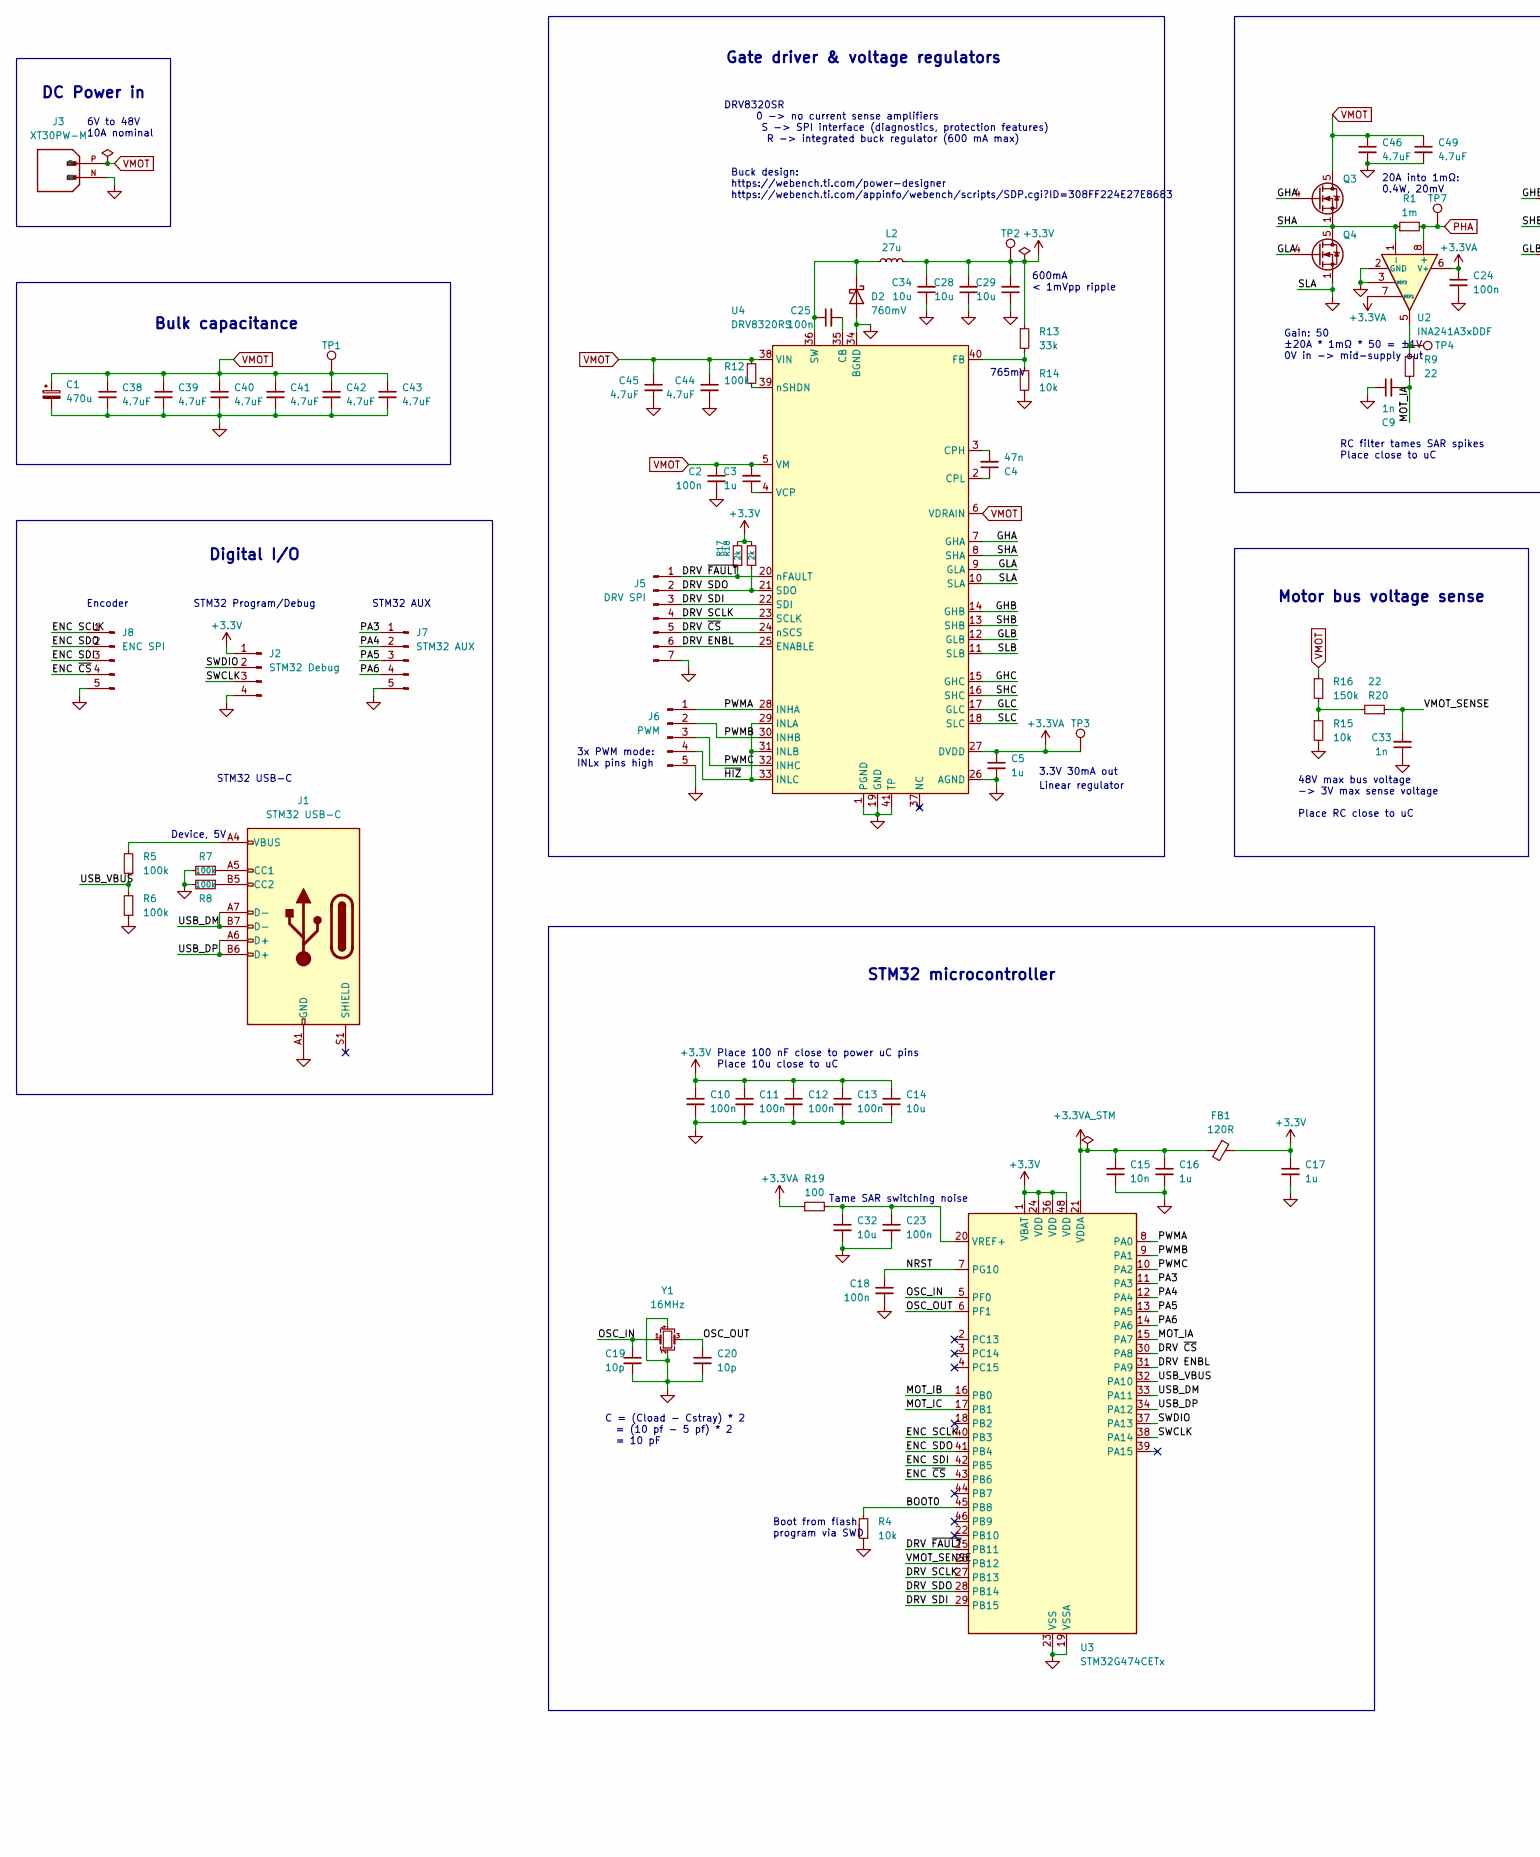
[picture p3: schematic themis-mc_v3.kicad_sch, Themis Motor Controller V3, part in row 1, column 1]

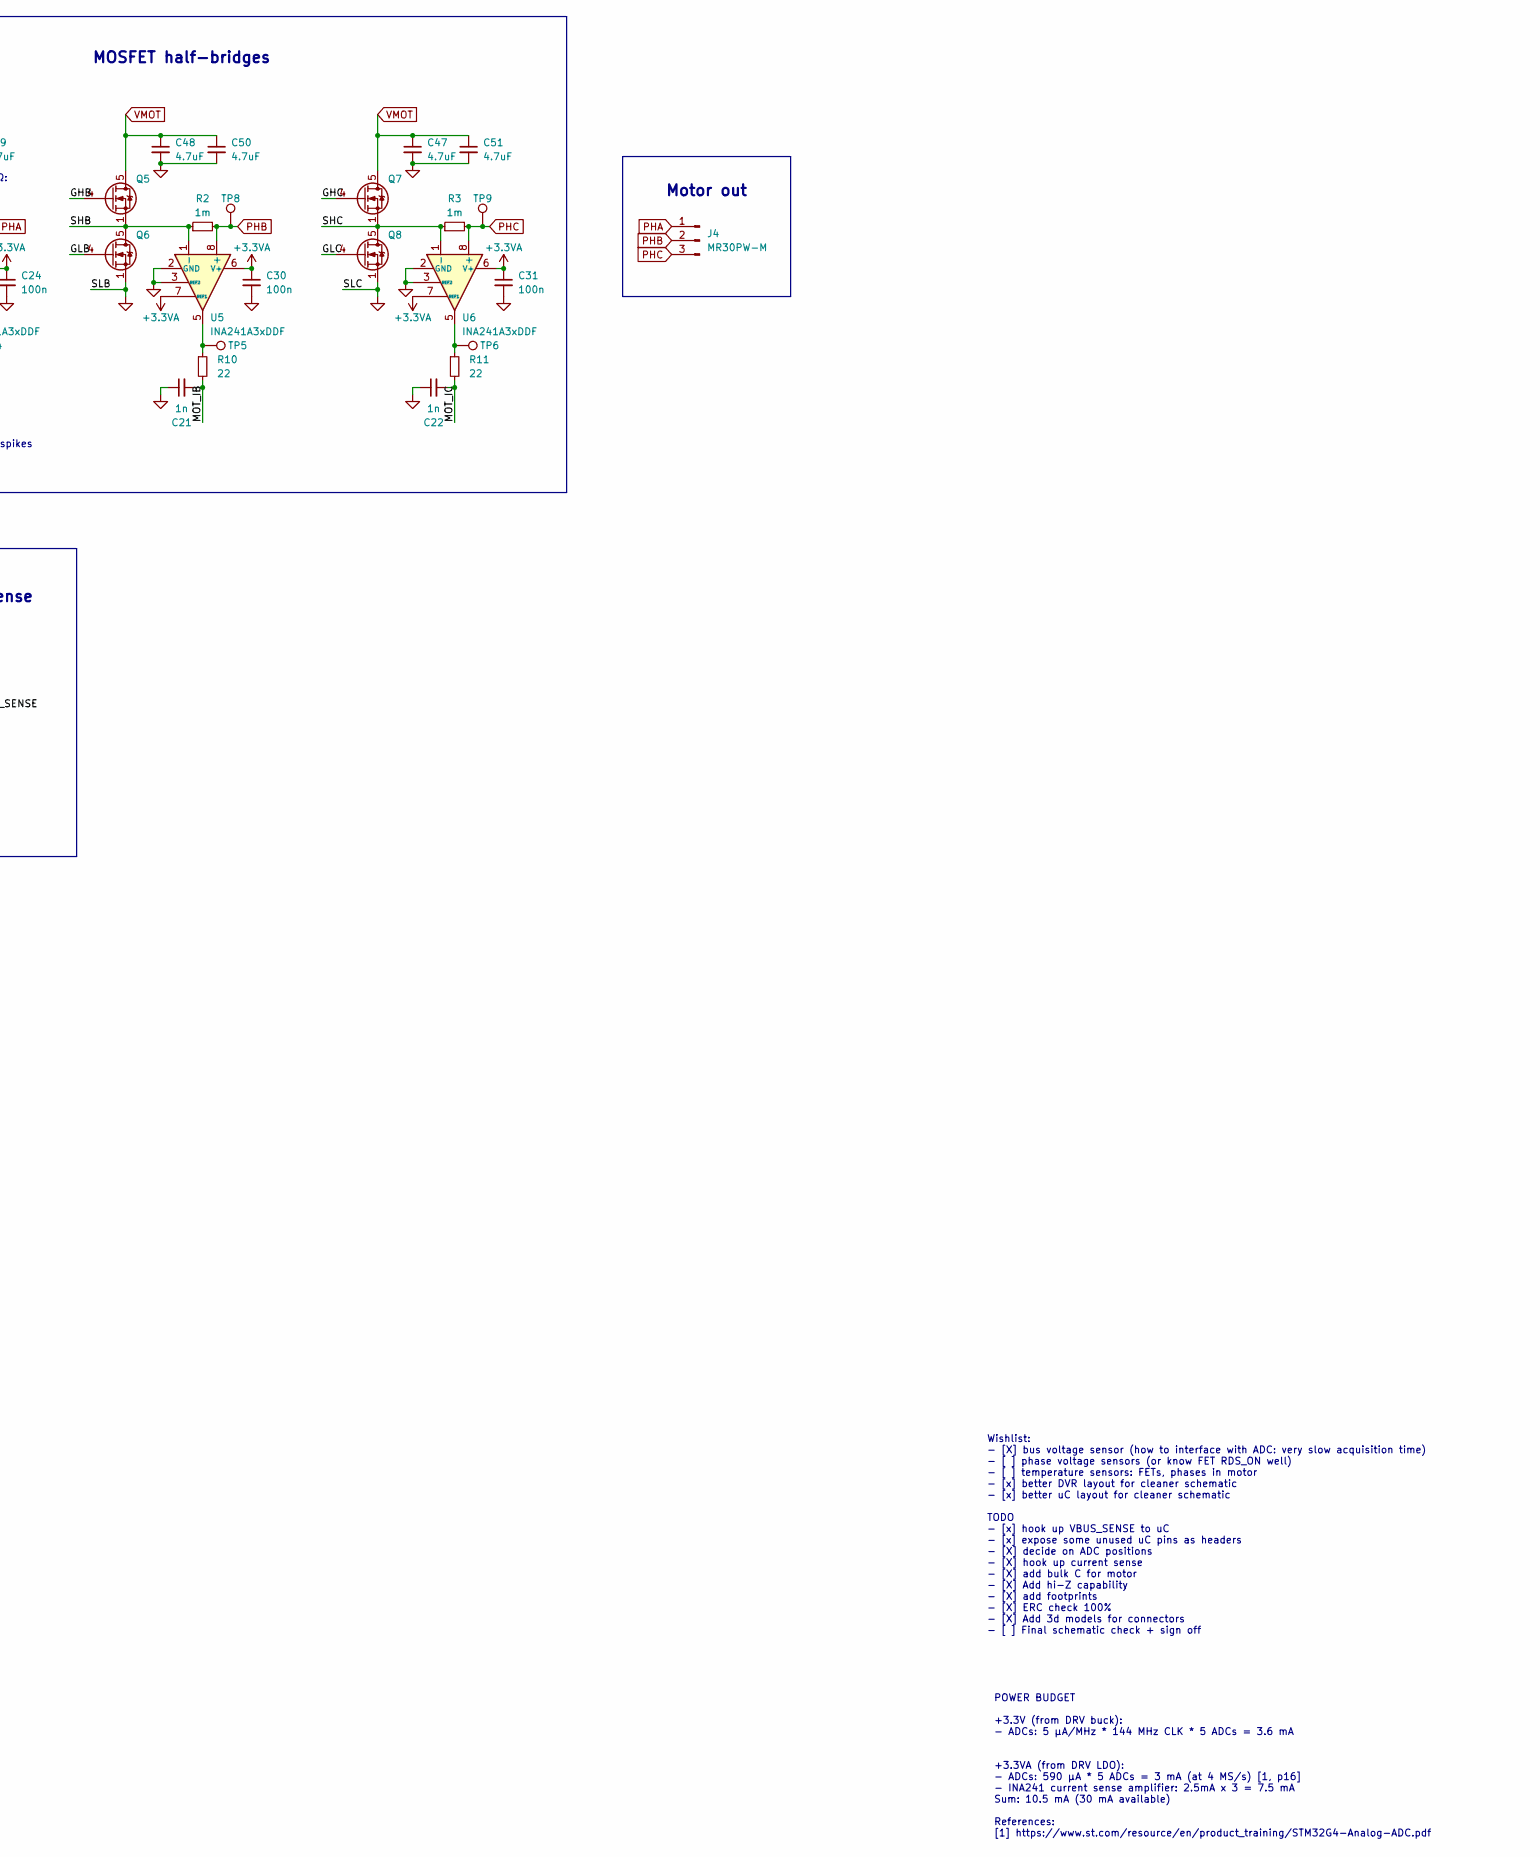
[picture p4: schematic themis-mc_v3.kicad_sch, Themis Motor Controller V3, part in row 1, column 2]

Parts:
C1: 470u; CP_Radial_D16.0mm_P7.50mm; MPN 100ZLH470MEFC16X31.5
C2, C25: 100n; C_0805_2012Metric; MPN CL21B104KCFWPNE
C3: 1u
C4: 47n; C_0805_2012Metric; MPN CL21B473KCFNNNE
C5, C16, C17: 1u; C_0805_2012Metric
C9, C21, C22, C33: 1n; C_0805_2012Metric
C10, C11, C12, C13, C18, C23, C24, C30, C31: 100n; C_0805_2012Metric
C14, C32: 10u; C_0805_2012Metric
C15: 10n; C_0805_2012Metric
C19, C20: 10p; C_0805_2012Metric
C28, C29, C34: 10u; C_0805_2012Metric; MPN C2012X5R1V156M125AC
C38, C39, C40, C41, C42, C43, C44, C45, C46, C47, C48, C49, C50, C51: 4.7uF; C_1206_3216Metric; MPN GRJ31CC72A475KE01K
D2: 760mV; Nexperia_CFP3_SOD-123W; MPN MBR1H100SFT3G
FB1: 120R; L_0805_2012Metric
J1: STM32 USB-C; USB_C_Receptacle_GCT_USB4105-xx-A_16P_TopMnt_Horizontal
J2: STM32 Debug; PinHeader_1x04_P2.54mm_Vertical
J3: XT30PW-M; AMASS_XT30PW-M_1x02_P2.50mm_Horizontal; MPN XT30PW-M
J4: MR30PW-M; AMASS_MR30PW-M_1x03_P3.50mm_Horizontal
J5: DRV SPI; PinHeader_1x07_P2.54mm_Vertical
J6: PWM; PinHeader_1x05_P2.54mm_Vertical
J7: STM32 AUX; PinHeader_1x05_P2.54mm_Vertical
J8: ENC SPI; PinHeader_1x05_P2.54mm_Vertical
L2: 27u; L_Bourns_SDR0604; MPN SDR0604-270YL
Q3, Q4, Q5, Q6, Q7, Q8: LFPAK56; MPN PSMN5R2-60YL
R1, R2, R3: 1m; R_2512_6332Metric; MPN CSNL2512FT1L00
R4, R14, R15: 10k; L_0805_2012Metric
R5, R6, R7, R8, R12: 100k; L_0805_2012Metric
R9, R10, R11, R20: 22; L_0805_2012Metric
R13: 33k; L_0805_2012Metric
R16: 150k; L_0805_2012Metric
R17, R18: 2k; L_0805_2012Metric
R19: 100; L_0805_2012Metric
TP1, TP2, TP3, TP4, TP5, TP6, TP7, TP8, TP9: TestPoint_Keystone_5010-5014_Multipurpose; MPN 5010-5014
U2, U5, U6: INA241A3xDDF; SOT-23-8; MPN INA241A3IDDFR
U3: STM32G474CETx; LQFP-48_7x7mm_P0.5mm
U4: DRV8320RS; VQFN-40-1EP_5x5mm_P0.4mm_EP3.5x3.5mm; MPN DRV8320RS
Y1: 16MHz; Crystal_SMD_3225-4Pin_3.2x2.5mm; MPN CS00527-16M

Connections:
+3.3V: C10.1, C11.1, C12.1, C13.1, C14.1, C17.1, C28.2, C29.2, C34.2, FB1.1, J2.1, L2.1, R13.1, R17.2, R18.2, TP2.1, U3.1 (VBAT), U3.24 (VDD), U3.36 (VDD), U3.48 (VDD)
+3.3VA: C5.1, C24.1, C30.1, C31.1, R19.1, TP3.1, U2.6 (V+), U2.7 (REF1), U4.27 (DVDD), U5.6 (V+), U5.7 (REF1), U6.6 (V+), U6.7 (REF1)
+3.3VA_STM: C15.1, C16.1, FB1.2, U3.21 (VDDA)
/BOOT0: R4.2, U3.45 (PB8)
/DRV ENBL: J5.6, U3.31 (PA9), U4.25 (ENABLE)
/DRV SCLK: J5.4, U3.27 (PB13), U4.23 (SCLK)
/DRV SDI: J5.3, U3.29 (PB15), U4.22 (SDI)
/DRV SDO: J5.2, R18.1, U3.28 (PB14), U4.21 (SDO)
/DRV ~CS: J5.5, U3.30 (PA8), U4.24 (nSCS)
/DRV ~FAULT: J5.1, R17.1, U3.25 (PB11), U4.20 (nFAULT)
/ENC SCLK: J8.1, U3.40 (PB3)
/ENC SDI: J8.3, U3.42 (PB5)
/ENC SDO: J8.2, U3.41 (PB4)
/ENC ~CS: J8.4, U3.43 (PB6)
/GHA: Q3.4 (G), U4.7 (GHA)
/GHB: Q5.4 (G), U4.14 (GHB)
/GHC: Q7.4 (G), U4.15 (GHC)
/GLA: Q4.4 (G), U4.9 (GLA)
/GLB: Q6.4 (G), U4.12 (GLB)
/GLC: Q8.4 (G), U4.17 (GLC)
/MOT_IA: C9.2, R9.2, U3.15 (PA7)
/MOT_IB: C21.2, R10.2, U3.16 (PB0)
/MOT_IC: C22.2, R11.2, U3.17 (PB1)
/NRST: C18.1, U3.7 (PG10)
/OSC_IN: C19.1, U3.5 (PF0), Y1.1
/OSC_OUT: C20.1, U3.6 (PF1), Y1.3
/PA3: J7.1, U3.11 (PA3)
/PA4: J7.2, U3.12 (PA4)
/PA5: J7.3, U3.13 (PA5)
/PA6: J7.4, U3.14 (PA6)
/PWMA: J6.1, U3.8 (PA0), U4.28 (INHA)
/PWMB: J6.2, U3.9 (PA1), U4.30 (INHB)
/PWMC: J6.3, U3.10 (PA2), U4.32 (INHC)
/SHA: Q3.1 (S), Q3.2 (S), Q3.3 (S), Q4.5 (D), R1.1, U2.1 (-), U4.8 (SHA)
/SHB: Q5.1 (S), Q5.2 (S), Q5.3 (S), Q6.5 (D), R2.1, U4.13 (SHB), U5.1 (-)
/SHC: Q7.1 (S), Q7.2 (S), Q7.3 (S), Q8.5 (D), R3.1, U4.16 (SHC), U6.1 (-)
/SWCLK: J2.3, U3.38 (PA14)
/SWDIO: J2.2, U3.37 (PA13)
/USB_DM: J1.A7 (D-), J1.B7 (D-), U3.33 (PA11)
/USB_DP: J1.A6 (D+), J1.B6 (D+), U3.34 (PA12)
/USB_VBUS: R5.1, R6.2, U3.32 (PA10)
/VMOT_SENSE: C33.2, R20.1, U3.26 (PB12)
/~HIZ: J6.4, U4.29 (INLA), U4.31 (INLB), U4.33 (INLC)
GND: C1.2, C2.2, C5.2, C9.1, C10.2, C11.2, C12.2, C13.2, C14.2, C15.2, C16.2, C17.2, C18.2, C19.2, C20.2, C21.1, C22.1, C23.2, C24.2, C28.1, C29.1, C30.2, C31.2, C32.2, C33.1, C34.1, C38.2, C39.2, C40.2, C41.2, C42.2, C43.2, C44.2, C45.2, C46.2, C47.2, C48.2, C49.2, C50.2, C51.2, D2.2 (A), J1.A1 (GND), J1.A12 (GND), J1.B1 (GND), J1.B12 (GND), J2.4, J3.N, J5.7, J6.5, J7.5, J8.5, Q4.1 (S), Q4.2 (S), Q4.3 (S), Q6.1 (S), Q6.2 (S), Q6.3 (S), Q8.1 (S), Q8.2 (S), Q8.3 (S), R4.1, R6.1, R7.2, R8.2, R14.2, R15.2, U2.2 (GND), U2.3 (REF2), U2.4 (GND), U3.19 (VSSA), U3.23 (VSS), U3.35 (VSS), U3.47 (VSS), U4.1 (PGND), U4.10 (SLA), U4.11 (SLB), U4.18 (SLC), U4.19 (GND), U4.26 (AGND), U4.34 (BGND), U4.41 (TP), U5.2 (GND), U5.3 (REF2), U5.4 (GND), U6.2 (GND), U6.3 (REF2), U6.4 (GND), Y1.2, Y1.4
unnamed: C25.1, D2.1 (K), L2.2, U4.36 (SW)
unnamed: J1.A5 (CC1), R7.1
unnamed: J1.B5 (CC2), R8.1
unnamed: J1.A4 (VBUS), J1.A9 (VBUS), J1.B4 (VBUS), J1.B9 (VBUS), R5.2
unnamed: R9.1, TP4.1, U2.5
unnamed: R10.1, TP5.1, U5.5
unnamed: R11.1, TP6.1, U6.5
unnamed: R15.1, R16.2, R20.2
unnamed: C23.1, C32.1, R19.2, U3.20 (VREF+)
unnamed: C25.2, U4.35 (CB)
unnamed: C4.2, U4.3 (CPH)
unnamed: C4.1, U4.2 (CPL)
unnamed: R13.2, R14.1, U4.40 (FB)
unnamed: C3.1, U4.4 (VCP)
unnamed: R12.2, U4.39 (nSHDN)
PHA: J4.1, R1.2, TP7.1, U2.8 (+)
PHB: J4.2, R2.2, TP8.1, U5.8 (+)
PHC: J4.3, R3.2, TP9.1, U6.8 (+)
VMOT: C1.1, C2.1, C3.2, C38.1, C39.1, C40.1, C41.1, C42.1, C43.1, C44.1, C45.1, C46.1, C47.1, C48.1, C49.1, C50.1, C51.1, J3.P, Q3.5 (D), Q5.5 (D), Q7.5 (D), R12.1, R16.1, TP1.1, U4.5 (VM), U4.6 (VDRAIN), U4.38 (VIN)

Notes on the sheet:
6V to 48V 10A nominal
STM32 USB-C
600mA < 1mVpp ripple
STM32 AUX
20A into 1mΩ: 0.4W, 20mV
Gain: 50 ±20A * 1mΩ * 50 = ±1V 0V in -> mid-supply out
MOSFET half-bridges
Linear regulator
48V max bus voltage -> 3V max sense voltage
Bulk capacitance
Motor out
Motor bus voltage sense
765mV
Place 100 nF close to power uC pins Place 10u close to uC
Gate driver & voltage regulators
3.3V 30mA out
Buck design: https://webench.ti.com/power-designer https://webench.ti.com/appinfo/webench/scripts/SDP.cgi?ID=308FF224E27E8683
Wishlist: - [X] bus voltage sensor (how to interface with ADC: very slow acquisition time) - [ ] phase voltage sensors (or know FET RDS_ON well) - [ ] temperature sensors: FETs, phases in motor - [x] better DVR layout for cleaner schematic - [x] better uC layout for cleaner schematic TODO - [x] hoo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
C = (Cload - Cstray) * 2 = (10 pf - 5 pf) * 2 = 10 pF
3x PWM mode: INLx pins high
Encoder
Digital I/O
Tame SAR switching noise
Device, 5V
DRV8320SR 0 -> no current sense amplifiers S -> SPI interface (diagnostics, protection features) R -> integrated buck regulator (600 mA max)
POWER BUDGET +3.3V (from DRV buck): - ADCs: 5 µA/MHz * 144 MHz CLK * 5 ADCs = 3.6 mA +3.3VA (from DRV LDO): - ADCs: 590 μA * 5 ADCs = 3 mA (at 4 MS/s) [1, p16] - INA241 current sense amplifier: 2.5mA x 3 = 7.5 mA Sum: 10.5 mA (30 mA available) References: [1] https://www.st.com/resource/en/product_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
Place RC close to uC
STM32 Program/Debug
Boot from flash, program via SWD
RC filter tames SAR spikes Place close to uC
DC Power in
STM32 microcontroller

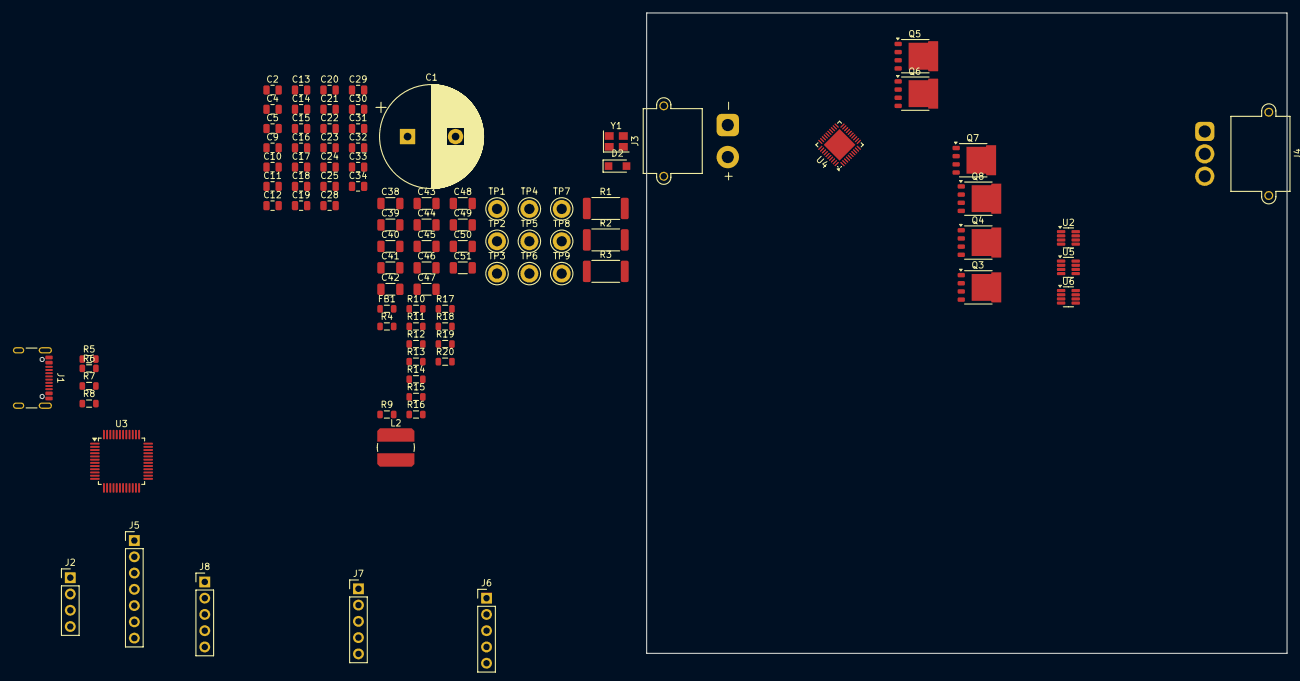
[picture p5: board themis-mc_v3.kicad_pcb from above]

Board: 2 copper layers, 100.0 x 100.0 mm, 94 parts (0 on the bottom side), 62 nets.

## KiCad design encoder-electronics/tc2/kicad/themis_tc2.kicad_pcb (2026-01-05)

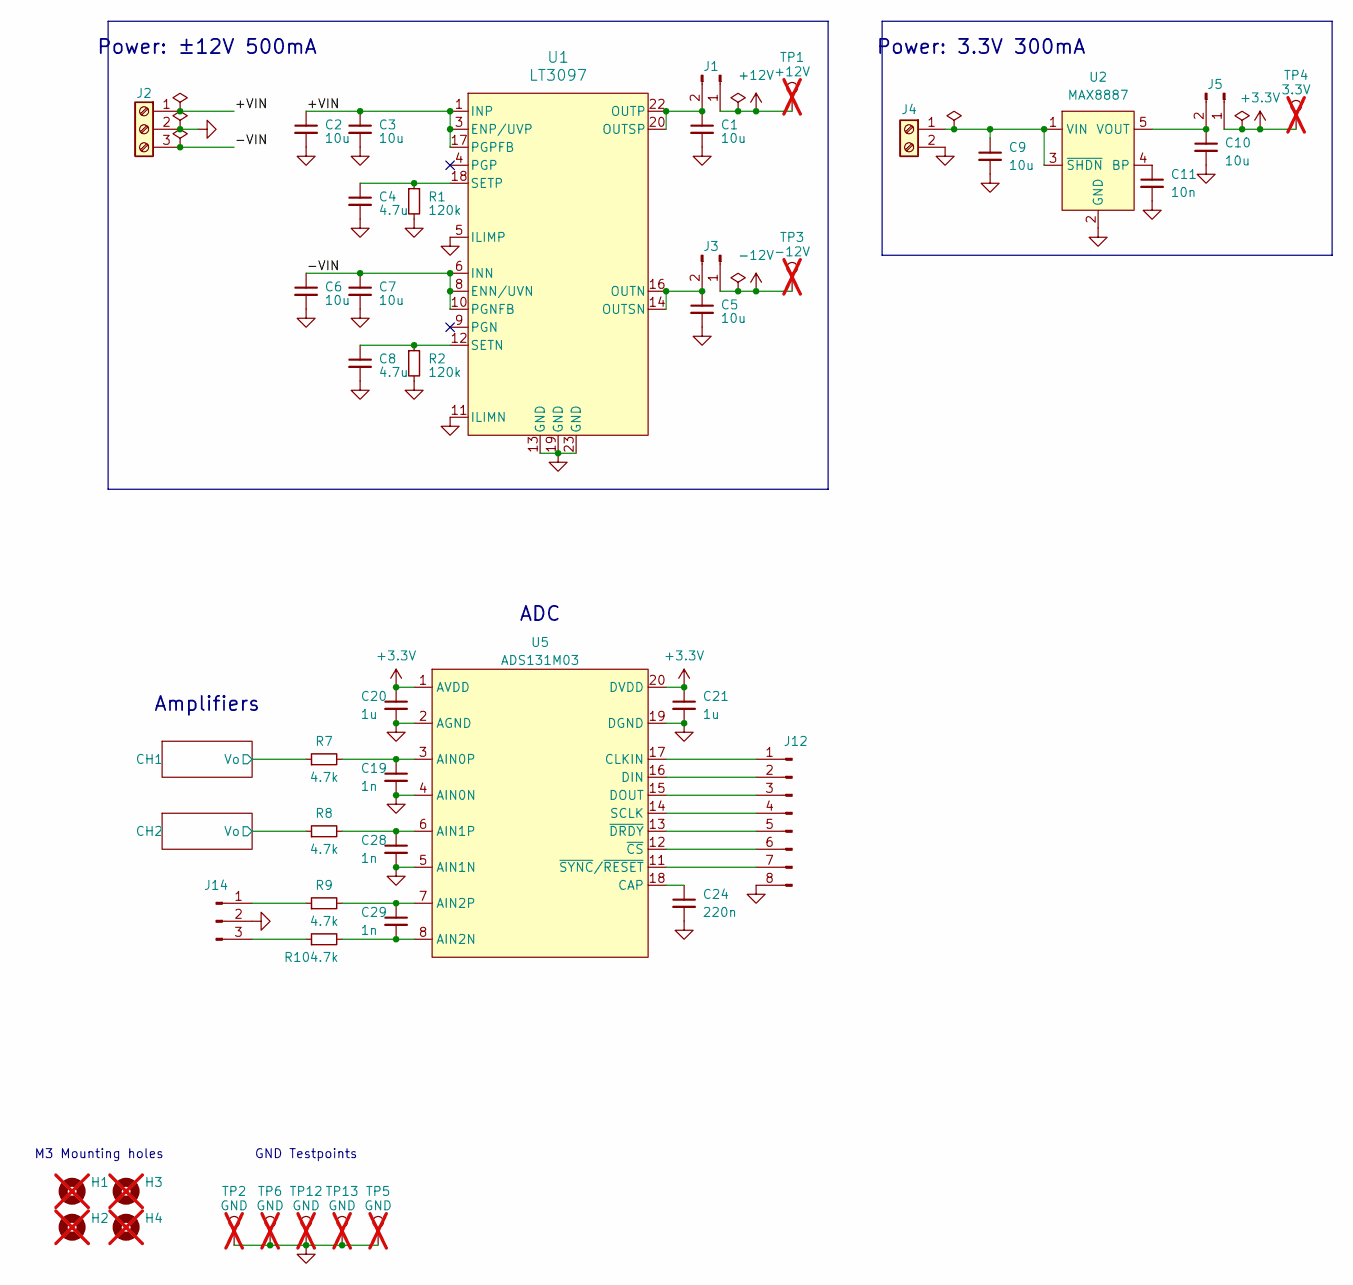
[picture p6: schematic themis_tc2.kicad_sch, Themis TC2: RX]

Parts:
C1, C2, C3, C5, C6, C7, C9, C10: 10u; C_0805_2012Metric; MPN GRM21BR61H106KE43L
C4, C8: 4.7u; C_0805_2012Metric; MPN GRM21BR61H475KE51L
C11: 10n; C_0805_2012Metric; MPN C0805C103K5RACTU
C19, C28, C29: 1n; C_0805_2012Metric; MPN C0805C102J5GACTU
C20, C21: 1u; C_0805_2012Metric; MPN CL21B105KBFNNNE
C24: 220n; C_0805_2012Metric; MPN CL21B224KBFNNNE
H1, H2, H3, H4: MountingHole; MountingHole_3.2mm_M3_DIN965; not fitted
J1, J3, J5: Conn_01x02_Pin; PinHeader_1x02_P2.54mm_Vertical; MPN 61300211121
J2: Screw_Terminal_01x03; TerminalBlock_TE_282834-3_1x03_P2.54mm_Horizontal; MPN 282834-3
J4: Screw_Terminal_01x02; TerminalBlock_TE_282834-2_1x02_P2.54mm_Horizontal; MPN 282834-2
J12: Conn_01x08_Pin; PinHeader_1x08_P2.54mm_Vertical; MPN 61300811121
J14: Conn_01x03_Pin; PinHeader_1x03_P2.54mm_Vertical; MPN 61300311121
R1, R2: 120k; R_0805_2012Metric; MPN RC0805FR-07120KL
R7, R8, R9, R10: 4.7k; R_0805_2012Metric; MPN RC0805FR-074K7L
TP1: +12V; TestPoint_Keystone_5010-5014_Multipurpose; not fitted
TP2, TP5, TP6, TP12, TP13: GND; TestPoint_Keystone_5010-5014_Multipurpose; not fitted
TP3: -12V; TestPoint_Keystone_5010-5014_Multipurpose; not fitted
TP4: 3.3V; TestPoint_Keystone_5010-5014_Multipurpose; not fitted
U1: LT3097; 05-08-7071_ADI; MPN LT3097ADJC#PBF
U2: MAX8887; SOT-23-5; MPN MAX8887EZK33+T
U5: ADS131M03; TSSOP-20_L6.5-W4.4-P0.65-LS6.4-BL; MPN ADS131M03QPWRQ1; LCSC Part C6123452

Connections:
+3.3V: C20.1, C21.1, J5.1, TP4.1, U5.1 (AVDD), U5.20 (DVDD)
+12V: J1.1, TP1.1; also elsewhere on the board
-12V: J3.1, TP3.1; also elsewhere on the board
/CH1/Vo: R7.1; also elsewhere on the board
/CH2/Vo: R8.1; also elsewhere on the board
GND: C1.2, C2.2, C3.2, C4.2, C5.2, C6.2, C7.2, C8.2, C9.2, C10.2, C11.2, C19.2, C20.2, C21.2, C24.2, C28.2, J2.2, J4.2, J12.8, J14.2, R1.2, R2.2, TP2.1, TP5.1, TP6.1, TP12.1, TP13.1, U1.5 (ILIMP), U1.11 (ILIMN), U1.13 (GND), U1.19 (GND), U1.23 (GND), U2.2 (GND), U5.2 (AGND), U5.4 (AIN0N), U5.5 (AIN1N), U5.19 (DGND); also elsewhere on the board
INN: C6.1, C7.1, J2.3, U1.6 (INN), U1.7 (INN), U1.8 (ENN/UVN), U1.10 (PGNFB), U1.24 (INN)
INP: C2.1, C3.1, J2.1, U1.1 (INP), U1.2 (INP), U1.3 (ENP/UVP), U1.17 (PGPFB)
unnamed: C1.1, J1.2, U1.20 (OUTSP), U1.21 (OUTP), U1.22 (OUTP)
unnamed: C5.1, J3.2, U1.14 (OUTSN), U1.15 (OUTN), U1.16 (OUTN)
unnamed: C9.1, J4.1, U2.1 (VIN), U2.3 (~SHDN)
unnamed: C10.1, J5.2, U2.5 (VOUT)
unnamed: J12.1, U5.17 (CLKIN)
unnamed: J12.2, U5.16 (DIN)
unnamed: J12.3, U5.15 (DOUT)
unnamed: J12.4, U5.14 (SCLK)
unnamed: J12.5, U5.13 (~DRDY)
unnamed: J12.6, U5.12 (~CS)
unnamed: J12.7, U5.11 (~SYNC/~RESET)
unnamed: J14.1, R9.1
unnamed: J14.3, R10.1
unnamed: C8.1, R2.1, U1.12 (SETN)
unnamed: C4.1, R1.1, U1.18 (SETP)
unnamed: C11.1, U2.4 (BP)
unnamed: C19.1, R7.2, U5.3 (AIN0P)
unnamed: C28.1, R8.2, U5.6 (AIN1P)
unnamed: C29.2, R10.2, U5.8 (AIN2N)
unnamed: C29.1, R9.2, U5.7 (AIN2P)
unnamed: C24.1, U5.18 (CAP)

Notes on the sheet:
ADC
M3 Mounting holes
GND Testpoints
Power: 3.3V 300mA
Amplifiers
Power: ±12V 500mA

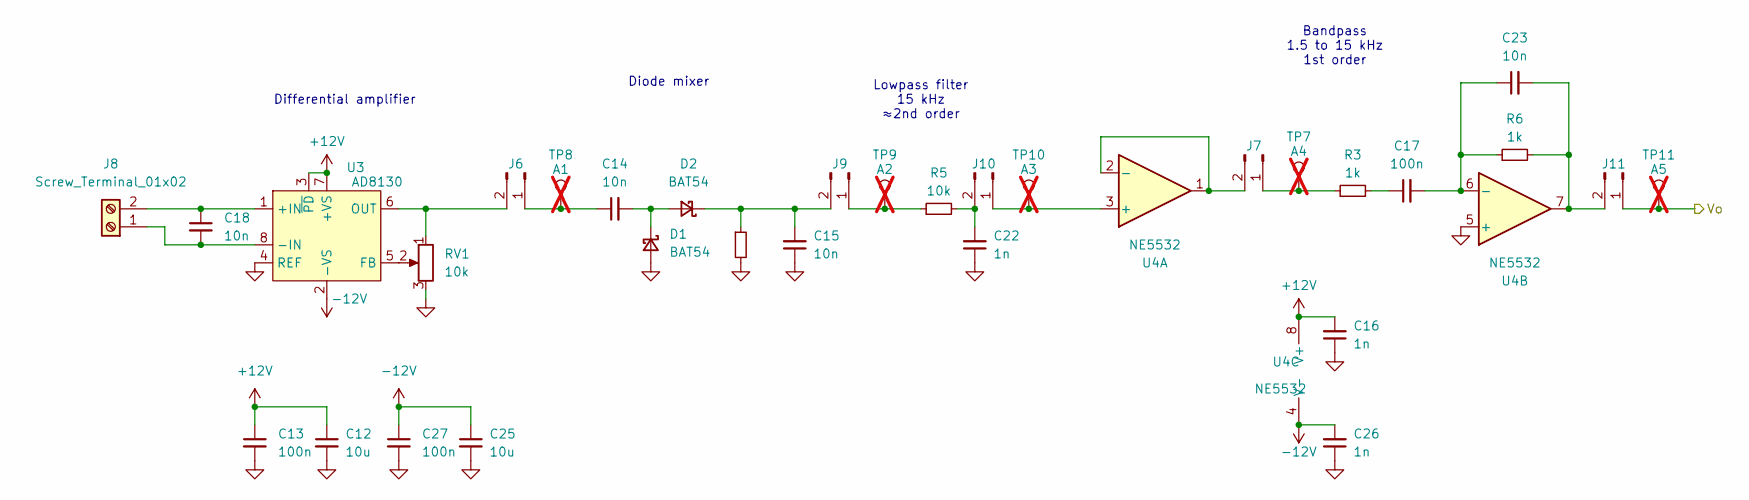
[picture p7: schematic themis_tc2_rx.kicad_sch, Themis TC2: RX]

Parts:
C12, C25: 10u; C_0805_2012Metric; MPN GRM21BR61H106KE43L
C13, C17, C27: 100n; C_0805_2012Metric; MPN C0805C104K5RACTU
C14, C15, C18, C23: 10n; C_0805_2012Metric; MPN C0805C103K5RACTU
C16, C22, C26: 1n; C_0805_2012Metric; MPN C0805C102J5GACTU
D1, D2: BAT54; D_SOD-323; MPN BAT54HT1G
J6, J7, J9, J10, J11: Conn_01x02_Pin; PinHeader_1x02_P2.54mm_Vertical; MPN 61300211121
J8: Screw_Terminal_01x02; TerminalBlock_TE_282834-2_1x02_P2.54mm_Horizontal; MPN 282834-2
R3, R4, R6: 1k; R_0805_2012Metric; MPN RC0805FR-071KL
R5: 10k; R_0805_2012Metric; MPN RC0805FR-0710KL
RV1: 10k; Potentiometer_Bourns_3296W_Vertical; MPN 3296W-1-103LF
TP7: A4; TestPoint_Keystone_5010-5014_Multipurpose; not fitted
TP8: A1; TestPoint_Keystone_5010-5014_Multipurpose; not fitted
TP9: A2; TestPoint_Keystone_5010-5014_Multipurpose; not fitted
TP10: A3; TestPoint_Keystone_5010-5014_Multipurpose; not fitted
TP11: A5; TestPoint_Keystone_5010-5014_Multipurpose; not fitted
U3: AD8130; SOIC-8_L4.9-W3.9-P1.27-LS6.0-BL; MPN AD8130ARMZ-REEL; LCSC Part C126440
U4: NE5532; SOIC-8_3.9x4.9mm_P1.27mm; MPN NE5532DR

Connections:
+12V: C12.1, C13.1, C16.2, U3.3 (~PD), U3.7 (+VS), U4.8 (V+); also elsewhere on the board
-12V: C25.1, C26.2, C27.1, U3.2 (-VS), U4.4 (V-); also elsewhere on the board
/CH1/Vo: J11.1, TP11.1; also elsewhere on the board
GND: C12.2, C13.2, C15.1, C16.1, C22.1, C25.2, C26.1, C27.2, D1.2 (A), R4.2, RV1.3, U3.4 (REF), U4.5 (+); also elsewhere on the board
unnamed: C17.1, R3.2
unnamed: C14.2, D1.1 (K), D2.2 (A)
unnamed: C15.2, D2.1 (K), J9.2, R4.1
unnamed: C14.1, J6.1, TP8.1
unnamed: J6.2, RV1.1, U3.6 (OUT)
unnamed: J7.1, R3.1, TP7.1
unnamed: J7.2, U4.1, U4.2 (-)
unnamed: C18.2, J8.1, U3.8 (-IN)
unnamed: C18.1, J8.2, U3.1 (+IN)
unnamed: J9.1, R5.1, TP9.1
unnamed: J10.1, TP10.1, U4.3 (+)
unnamed: C22.2, J10.2, R5.2
unnamed: C23.2, J11.2, R6.2, U4.7
unnamed: RV1.2, U3.5 (FB)
unnamed: C17.2, C23.1, R6.1, U4.6 (-)

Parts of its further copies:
C30, C39: 10u; C_0805_2012Metric; MPN GRM21BR61H106KE43L
C31, C34, C40: 100n; C_0805_2012Metric; MPN C0805C104K5RACTU
C32, C33, C36, C38: 10n; C_0805_2012Metric; MPN C0805C103K5RACTU
C35, C37, C41: 1n; C_0805_2012Metric; MPN C0805C102J5GACTU
D3, D4: BAT54; D_SOD-323; MPN BAT54HT1G
J13, J15, J17, J18, J19: Conn_01x02_Pin; PinHeader_1x02_P2.54mm_Vertical; MPN 61300211121
J16: Screw_Terminal_01x02; TerminalBlock_TE_282834-2_1x02_P2.54mm_Horizontal; MPN 282834-2
R11, R12, R14: 1k; R_0805_2012Metric; MPN RC0805FR-071KL
R13: 10k; R_0805_2012Metric; MPN RC0805FR-0710KL
RV2: 10k; Potentiometer_Bourns_3296W_Vertical; MPN 3296W-1-103LF
TP14: A4; TestPoint_Keystone_5010-5014_Multipurpose; not fitted
TP15: A1; TestPoint_Keystone_5010-5014_Multipurpose; not fitted
TP16: A2; TestPoint_Keystone_5010-5014_Multipurpose; not fitted
TP17: A3; TestPoint_Keystone_5010-5014_Multipurpose; not fitted
TP18: A5; TestPoint_Keystone_5010-5014_Multipurpose; not fitted
U6: AD8130; SOIC-8_L4.9-W3.9-P1.27-LS6.0-BL; MPN AD8130ARMZ-REEL; LCSC Part C126440
U7: NE5532; SOIC-8_3.9x4.9mm_P1.27mm; MPN NE5532DR

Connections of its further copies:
+12V: C30.1, C31.1, C35.2, U6.3 (~PD), U6.7 (+VS), U7.8 (V+); also elsewhere on the board
-12V: C39.1, C40.1, C41.2, U6.2 (-VS), U7.4 (V-); also elsewhere on the board
/CH2/Vo: J19.1, TP18.1; also elsewhere on the board
GND: C30.2, C31.2, C33.1, C35.1, C37.1, C39.2, C40.2, C41.1, D3.2 (A), R12.2, RV2.3, U6.4 (REF), U7.5 (+); also elsewhere on the board
unnamed: C34.1, R11.2
unnamed: C32.2, D3.1 (K), D4.2 (A)
unnamed: C33.2, D4.1 (K), J17.2, R12.1
unnamed: C32.1, J13.1, TP15.1
unnamed: J13.2, RV2.1, U6.6 (OUT)
unnamed: J15.1, R11.1, TP14.1
unnamed: J15.2, U7.1, U7.2 (-)
unnamed: C36.2, J16.1, U6.8 (-IN)
unnamed: C36.1, J16.2, U6.1 (+IN)
unnamed: J17.1, R13.1, TP16.1
unnamed: J18.1, TP17.1, U7.3 (+)
unnamed: C37.2, J18.2, R13.2
unnamed: C38.2, J19.2, R14.2, U7.7
unnamed: RV2.2, U6.5 (FB)
unnamed: C34.2, C38.1, R14.1, U7.6 (-)

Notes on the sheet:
Differential amplifier
Diode mixer
Bandpass 1.5 to 15 kHz 1st order
Lowpass filter 15 kHz ≈2nd order

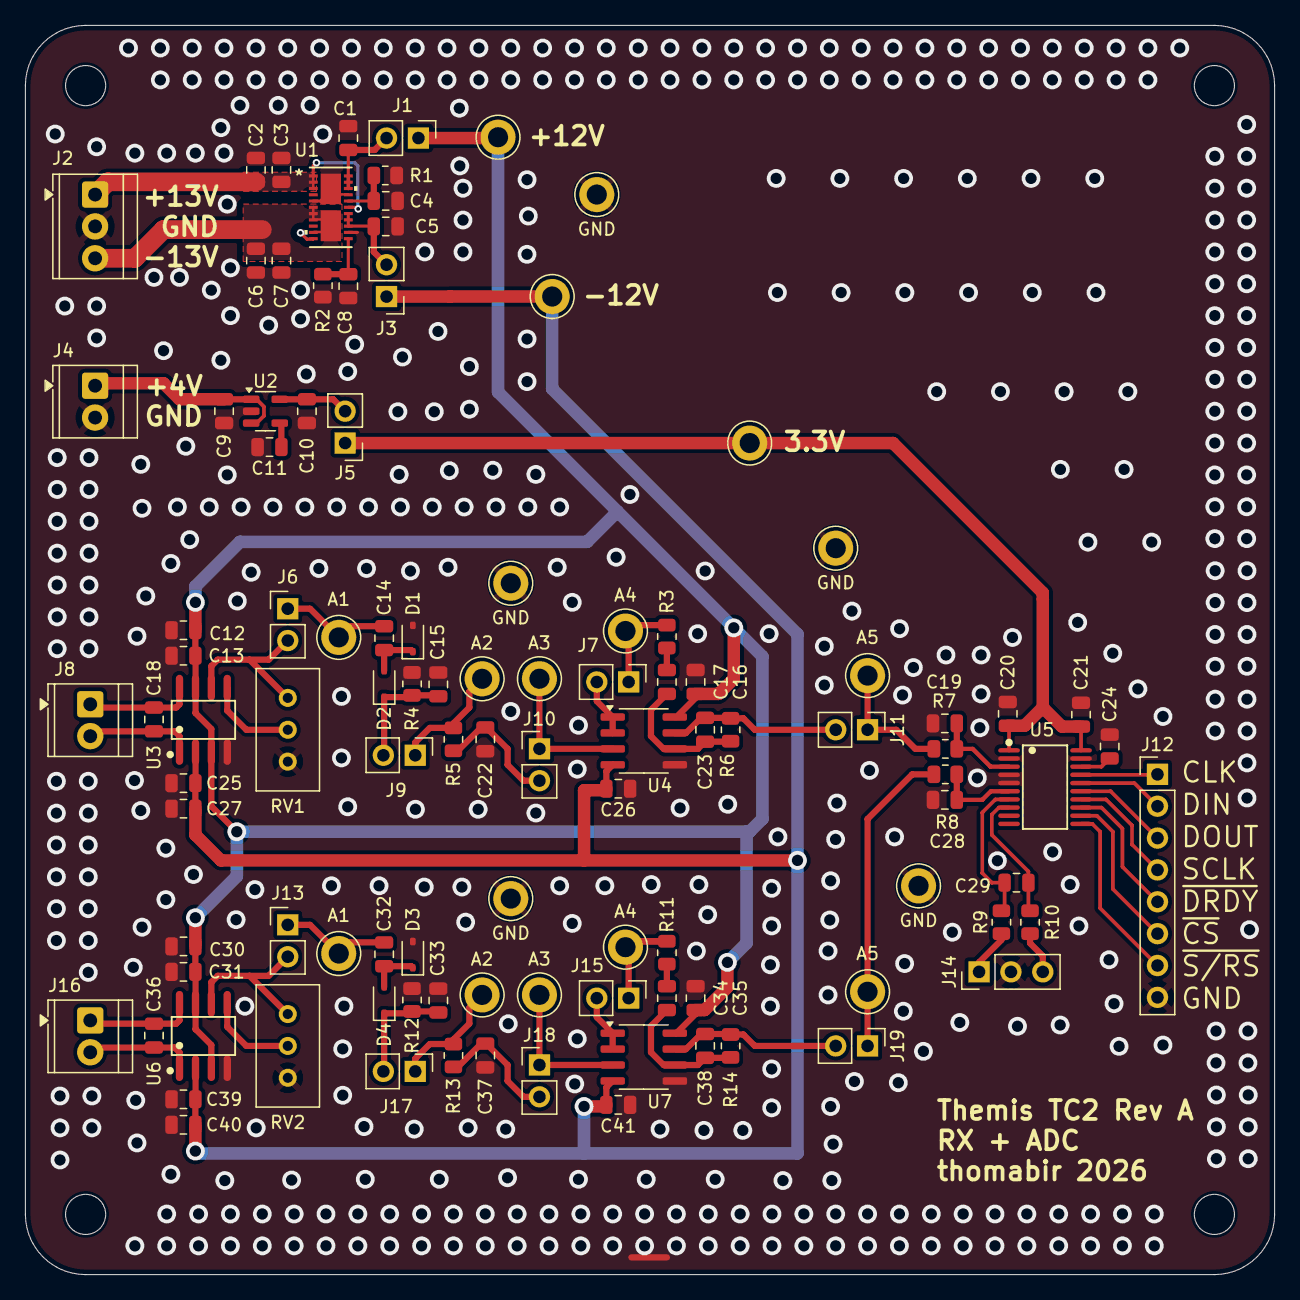
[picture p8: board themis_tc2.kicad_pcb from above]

Board: 4 copper layers, 99.6 x 99.6 mm, 109 parts (0 on the bottom side), 59 nets.

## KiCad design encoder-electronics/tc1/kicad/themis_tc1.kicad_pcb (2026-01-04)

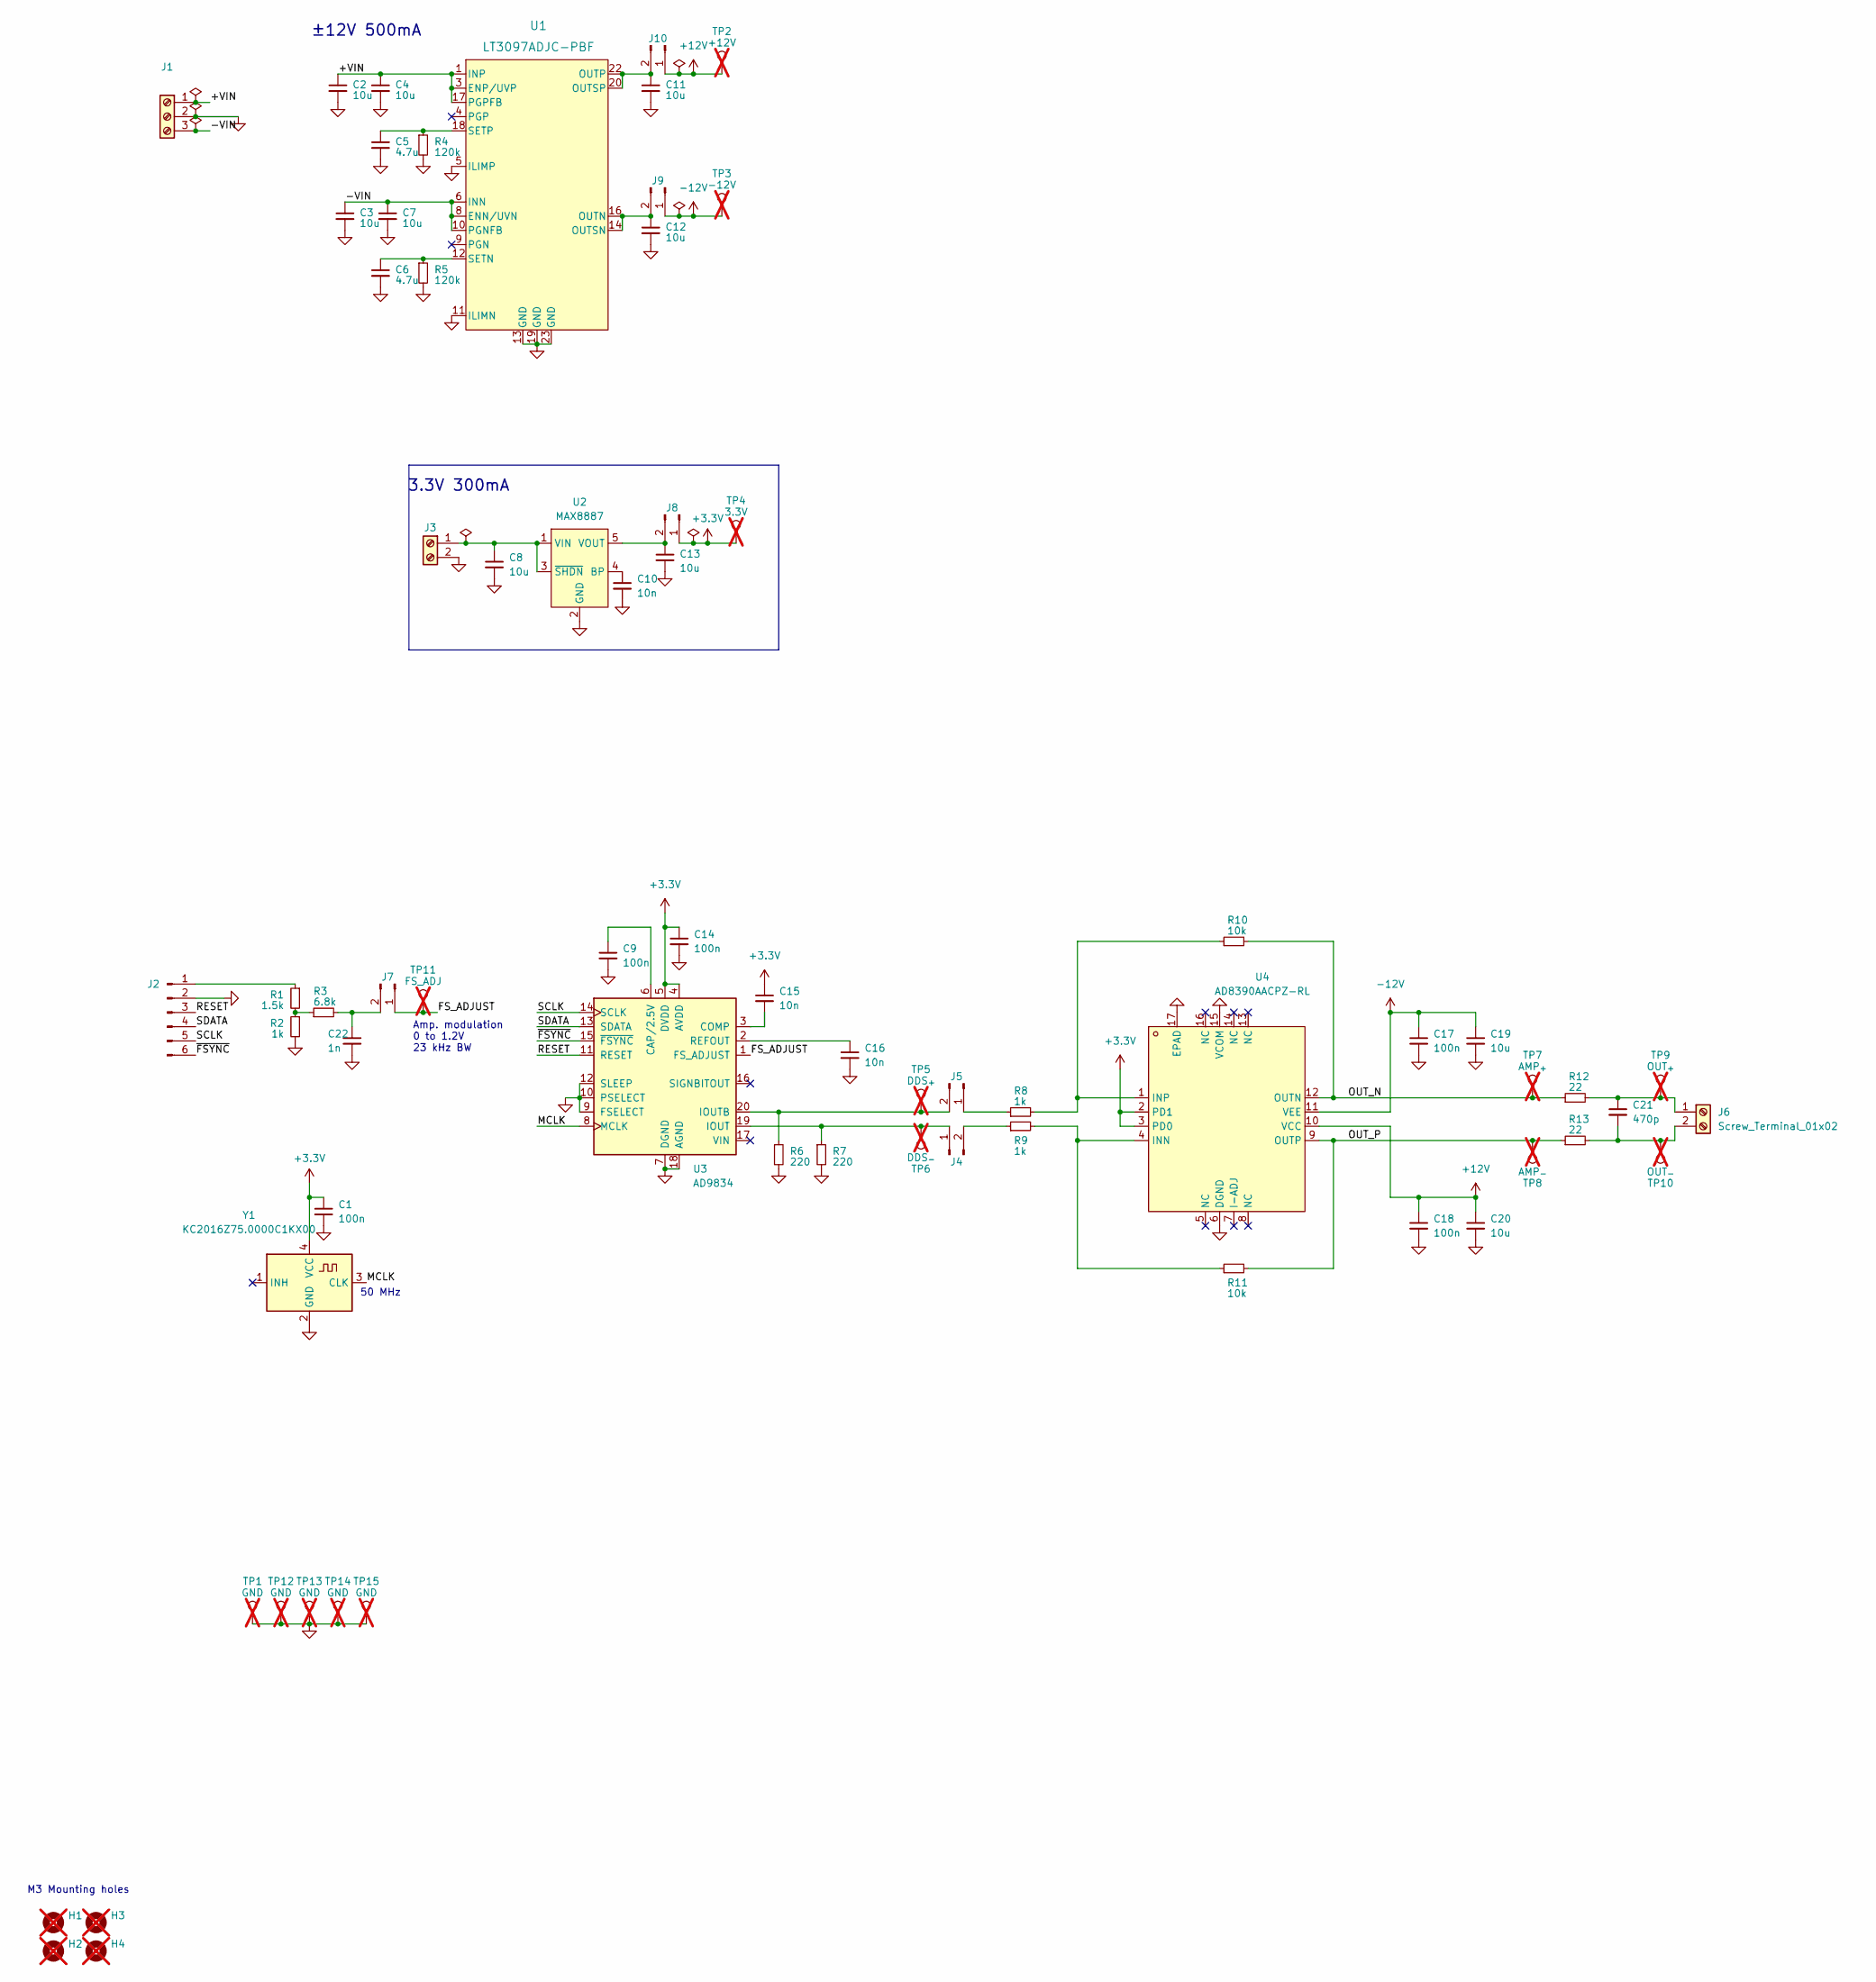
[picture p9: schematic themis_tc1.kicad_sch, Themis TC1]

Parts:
C1, C9, C14, C17, C18: 100n; C_0805_2012Metric
C2, C3, C4, C7, C8, C11, C12, C13, C19, C20: 10u; C_0805_2012Metric
C5, C6: 4.7u; C_0805_2012Metric
C10, C15, C16: 10n; C_0805_2012Metric
C21: 470p; C_0805_2012Metric
C22: 1n; C_0805_2012Metric
H1, H2, H3, H4: MountingHole; MountingHole_3.2mm_M3_DIN965; not fitted
J1: Screw_Terminal_01x03; TerminalBlock_TE_282834-3_1x03_P2.54mm_Horizontal
J2: Conn_01x06_Pin; PinHeader_1x06_P2.54mm_Vertical
J3: Screw_Terminal_01x02; TerminalBlock_TE_282834-2_1x02_P2.54mm_Horizontal; MPN 282834-2
J4, J5, J7, J8, J9, J10: Conn_01x02_Pin; PinHeader_1x02_P2.54mm_Vertical
J6: Screw_Terminal_01x02; TerminalBlock_TE_282834-2_1x02_P2.54mm_Horizontal
R1: 1.5k; R_0805_2012Metric
R2, R8, R9: 1k; R_0805_2012Metric
R3: 6.8k; R_0805_2012Metric
R4, R5: 120k; R_0805_2012Metric
R6, R7: 220; R_0805_2012Metric
R10, R11: 10k; R_0805_2012Metric
R12, R13: 22; R_0805_2012Metric
TP1, TP12, TP13, TP14, TP15: GND; TestPoint_Keystone_5010-5014_Multipurpose; not fitted
TP2: +12V; TestPoint_Keystone_5010-5014_Multipurpose; not fitted
TP3: -12V; TestPoint_Keystone_5010-5014_Multipurpose; not fitted
TP4: 3.3V; TestPoint_Keystone_5010-5014_Multipurpose; not fitted
TP5: DDS_{+}; TestPoint_Keystone_5010-5014_Multipurpose; not fitted
TP6: DDS_{-}; TestPoint_Keystone_5010-5014_Multipurpose; not fitted
TP7: AMP_{+}; TestPoint_Keystone_5010-5014_Multipurpose; not fitted
TP8: AMP_{-}; TestPoint_Keystone_5010-5014_Multipurpose; not fitted
TP9: OUT_{+}; TestPoint_Keystone_5010-5014_Multipurpose; not fitted
TP10: OUT_{-}; TestPoint_Keystone_5010-5014_Multipurpose; not fitted
TP11: FS_ADJ; TestPoint_Keystone_5010-5014_Multipurpose; not fitted
U1: LT3097ADJC-PBF; 05-08-7071_ADI
U2: MAX8887; SOT-23-5; MPN MAX8887
U3: AD9834; TSSOP-20_4.4x6.5mm_P0.65mm
U4: AD8390AACPZ-RL; LFCSP-16_L4.0-W4.0-P0.65-TL-EP2.0; LCSC Part C652757
Y1: KC2016Z75.0000C1KX00; Crystal_SMD_2016-4Pin_2.0x1.6mm

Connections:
+3.3V: C1.1, C14.1, C15.1, J8.1, TP4.1, U3.4 (AVDD), U3.5 (DVDD), U4.2 (PD1), U4.3 (PD0), Y1.4 (VCC)
+12V: C18.1, C20.1, J10.1, TP2.1, U4.10 (VCC)
-12V: C17.1, C19.1, J9.1, TP3.1, U4.11 (VEE)
/FS_ADJUST: J7.1, TP11.1, U3.1 (FS_ADJUST)
/MCLK: U3.8 (MCLK), Y1.3 (CLK)
/OUT_N: R10.2, R12.1, TP7.1, U4.12 (OUTN)
/OUT_P: R11.2, R13.1, TP8.1, U4.9 (OUTP)
/RESET: J2.3, U3.11 (RESET)
/SCLK: J2.5, U3.14 (SCLK)
/SDATA: J2.4, U3.13 (SDATA)
/~FSYNC: J2.6, U3.15 (~FSYNC)
GND: C1.2, C2.2, C3.2, C4.2, C5.2, C6.2, C7.2, C8.2, C9.2, C10.2, C11.2, C12.2, C13.2, C14.2, C16.2, C17.2, C18.2, C19.2, C20.2, C22.2, J1.2, J2.2, J3.2, R2.2, R4.2, R5.2, R6.2, R7.2, TP1.1, TP12.1, TP13.1, TP14.1, TP15.1, U1.5 (ILIMP), U1.11 (ILIMN), U1.13 (GND), U1.19 (GND), U1.23 (GND), U2.2 (GND), U3.7 (DGND), U3.9 (FSELECT), U3.10 (PSELECT), U3.12 (SLEEP), U3.18 (AGND), U4.6 (DGND), U4.15 (VCOM), U4.17 (EPAD), Y1.2 (GND)
INN: C3.1, C7.1, J1.3, U1.6 (INN), U1.7 (INN), U1.8 (ENN/UVN), U1.10 (PGNFB), U1.24 (INN)
INP: C2.1, C4.1, J1.1, U1.1 (INP), U1.2 (INP), U1.3 (ENP/UVP), U1.17 (PGPFB)
unnamed: J2.1, R1.1
unnamed: C8.1, J3.1, U2.1 (VIN), U2.3 (~SHDN)
unnamed: J4.1, R7.1, TP6.1, U3.19 (IOUT)
unnamed: J4.2, R9.1
unnamed: J5.1, R8.1
unnamed: J5.2, R6.1, TP5.1, U3.20 (IOUTB)
unnamed: C21.1, J6.1, R12.2, TP9.1
unnamed: C21.2, J6.2, R13.2, TP10.1
unnamed: C22.1, J7.2, R3.2
unnamed: C13.1, J8.2, U2.5 (VOUT)
unnamed: C12.1, J9.2, U1.14 (OUTSN), U1.15 (OUTN), U1.16 (OUTN)
unnamed: C11.1, J10.2, U1.20 (OUTSP), U1.21 (OUTP), U1.22 (OUTP)
unnamed: R1.2, R2.1, R3.1
unnamed: C6.1, R5.1, U1.12 (SETN)
unnamed: C5.1, R4.1, U1.18 (SETP)
unnamed: C10.1, U2.4 (BP)
unnamed: C9.1, U3.6 (CAP/2.5V)
unnamed: C15.2, U3.3 (COMP)
unnamed: C16.1, U3.2 (REFOUT)
unnamed: R9.2, R11.1, U4.4 (INN)
unnamed: R8.2, R10.1, U4.1 (INP)

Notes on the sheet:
M3 Mounting holes
50 MHz
Amp. modulation 0 to 1.2V 23 kHz BW
3.3V 300mA
±12V 500mA

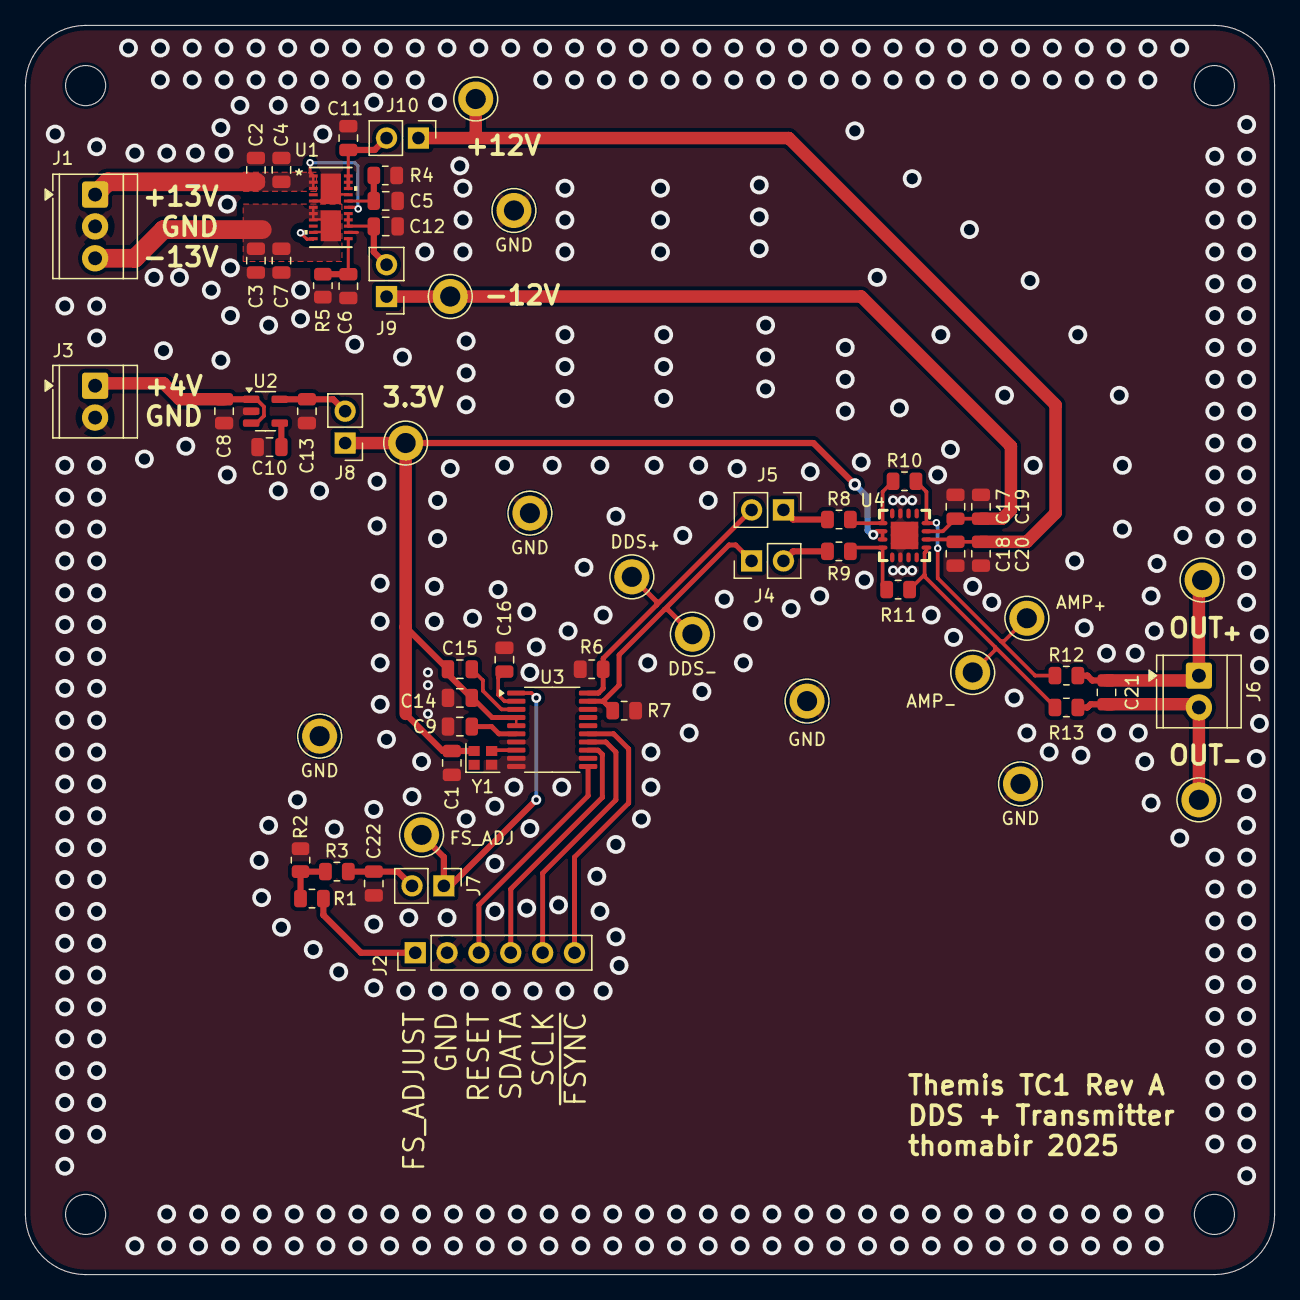
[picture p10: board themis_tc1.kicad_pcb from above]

Board: 4 copper layers, 99.6 x 99.6 mm, 69 parts (0 on the bottom side), 35 nets.

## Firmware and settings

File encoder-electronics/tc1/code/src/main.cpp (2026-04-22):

// TC1 bringup firmware — serial command shim for interactive DDS control.
// Not intended as production firmware; see AD9834.h for the reusable driver.

#include <Arduino.h>
#include "dds_controller.hpp"
#include "cmd_parser.hpp"

static constexpr int     PIN_FS_ADJUST         = 6;
static constexpr int     PIN_RESET             = 9;
static constexpr int     PIN_FSYNC             = 10;
static constexpr long    MCLK_HZ              = 75000000L;
// FS_ADJUST is current-sink: raw=0 → max output amplitude, raw=230 → min.
static constexpr uint8_t AMP_RAW_AT_MAX_OUTPUT = 0;
static constexpr uint8_t AMP_RAW_AT_MIN_OUTPUT = 230;
static constexpr int     CARRIER_AMP_AC_INIT   = 50;

static DdsController dds(PIN_FSYNC, PIN_RESET, MCLK_HZ,
                         PIN_FS_ADJUST, AMP_RAW_AT_MAX_OUTPUT, AMP_RAW_AT_MIN_OUTPUT);
static CmdParser     parser;

void setup() {
  Serial.begin(115200);
  while (!Serial && millis() < 2000) {}

  dds.begin(1e6f, CARRIER_AMP_AC_INIT);

  CmdParser::print_help();
  parser.print_state(dds);
}

void loop() {
  static char    buf[64];
  static uint8_t pos = 0;

  while (Serial.available()) {
    char c = Serial.read();
    if (c == '\n' || c == '\r') {
      if (pos > 0) {
        buf[pos] = '\0';
        parser.handle(buf, dds);
        pos = 0;
      }
    } else if (pos < sizeof(buf) - 1) {
      buf[pos++] = c;
    }
  }
}

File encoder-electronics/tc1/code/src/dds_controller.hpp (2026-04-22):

#pragma once

// Hardware interface boundary for the TC1 signal generator.
// Owns the AD9834 DDS and the FS_ADJUST amplitude modulator.
// main.cpp and CmdParser include only this header — never AD9834.h or
// amplitude_modulator.hpp directly. Swapping the DDS IC means updating only
// this file.

#include "AD9834.h"
#include "amplitude_modulator.hpp"

class DdsController {
 public:
  // All hardware pin assignments and amplitude-mapping constants in one place.
  DdsController(int pin_fsync, int pin_reset, long mclk_hz,
                int pin_fs_adjust,
                uint8_t amp_raw_at_max, uint8_t amp_raw_at_min)
      : _dds(),
        _mod(pin_fs_adjust, amp_raw_at_max, amp_raw_at_min),
        _pin_fsync(pin_fsync),
        _pin_reset(pin_reset),
        _mclk_hz(mclk_hz) {}

  // Full hardware initialisation. Call from setup() after Serial.begin().
  // Configures RESET pin, DDS, and AM modulator (PWM + IntervalTimer).
  void begin(float freq_init, int carrier_amp_ac_init,
             float am_isr_rate_hz = 200000.0f) {
    pinMode(_pin_reset, OUTPUT);
    digitalWrite(_pin_reset, LOW); // deassert reset (active-low)
    _dds.begin(_pin_fsync, _mclk_hz);
    _dds.update_freq(freq_init);
    _mod.begin(carrier_amp_ac_init, am_isr_rate_hz);
  }

  // --- Carrier ---

  void set_freq(float hz)     { _dds.update_freq(hz); }
  void set_mode(DdsMode mode) { _dds.update_mode(mode); }

  // Corrected amplitude [0, 100] — 0 = off, 100 = maximum output.
  void set_carrier_amp_ac(int ac)       { _mod.set_carrier_amp_ac(ac); }

  // Raw PWM [0, 255]. Converted to corrected scale internally so modulation
  // math keeps working after an 'a' command.
  void set_carrier_amp_raw(uint8_t raw) { _mod.set_carrier_amp_raw(raw); }

  // --- Amplitude modulation ---

  void set_mod_enabled(bool en)   { _mod.set_mod_enabled(en); }
  void set_mod_index(float idx)   { _mod.set_mod_index(idx); }
  void set_mod_freq(float hz)     { _mod.set_mod_freq(hz); }
  void set_mod_phase(float deg)   { _mod.set_mod_phase(deg); }

  // --- Getters (used by CmdParser::print_state and freq validation) ---

  float   get_freq()     const { return _dds.get_freq(); }
  float   get_freq_min() const { return 1.0f; }
  float   get_freq_max() const { return float(_mclk_hz) / 2.0f; }
  DdsMode get_mode()     const { return _dds.get_mode(); }

  // Returns -1 when raw 'a' command was last used; [0, 100] otherwise.
  int     get_carrier_amp_ac()  const { return _mod.get_carrier_amp_ac(); }
  uint8_t get_carrier_amp_raw() const { return _mod.get_carrier_amp_raw(); }

  bool  get_mod_enabled()   const { return _mod.get_mod_enabled(); }
  float get_mod_index()     const { return _mod.get_mod_index(); }
  float get_mod_freq()      const { return _mod.get_mod_freq(); }
  float get_mod_phase_deg() const { return _mod.get_mod_phase_deg(); }

 private:
  AD9834             _dds;
  AmplitudeModulator _mod;
  int                _pin_fsync;
  int                _pin_reset;
  long               _mclk_hz;
};

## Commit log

2026-01-04 TC1 (DDS) Rev. A
    [themis_tc1.kicad_pcb, themis_tc1.kicad_sch]
2026-01-04 TC2 (RX) Rev. A
    [themis_tc2.kicad_pcb, themis_tc2.kicad_sch, themis_tc2_rx.kicad_sch]
2026-01-05 Generate iBOM for TC2
    [themis_tc2.kicad_pcb]
2026-04-20 TC1 bringup: AD9834 DDS producing 1 MHz sine wave
    - Fix MCLK_HZ: oscillator is 75 MHz (BOM was correct, schematic was wrong)
    - Fix root cause of silent DDS: RESET pin was floating, holding chip in
    reset. Drive RESET LOW before initialising DDS, and construct AD9834
    object inside setup() so SPI is ready.
    - Add teensy-cli upload protocol to platformio.ini
    - Add AD9834 Arduino library (modified from AliBarber/AD9834)
    - Add AD9834 datasheet
    - Add notes/AD9834.md with register map, SPI notes, and lessons learned
    - Update project notebook with bringup session
    [themis_tc1.kicad_sch]
2026-04-22 tc1: add corrected amplitude command 'ac' (0–100)
    [main.cpp]
2026-04-22 tc1: add amplitude modulation with DdsController interface
    Introduce sinusoidal AM on the FS_ADJUST carrier amplitude:
    - New AmplitudeModulator: IntervalTimer ISR at 200 kHz drives FS_ADJUST PWM;
    modulation math a(t) = carrier*(1 + index*cos(acc + phase)) in the ISR.
    - New DdsController: hardware interface boundary that owns AD9834 +
    AmplitudeModulator. main.cpp and CmdParser no longer include AD9834.h
    directly — swapping the DDS IC only requires updating dds_controller.hpp.
    - CmdParser refactored to be fully stateless; dispatches on whole token
    (strcmp) to disambiguate m/me/mi/mf/mp.
    - New serial commands: me <on|off>, mi <0-1>, mf <Hz>, mp <deg>.
    - main.cpp reduced to minimal wir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
    [amplitude_modulator.hpp, dds_controller.hpp, main.cpp]
